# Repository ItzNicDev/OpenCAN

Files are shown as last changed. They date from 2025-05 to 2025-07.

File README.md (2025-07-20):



## 🔍 Project Overview

**OpenCAN** is a microcontroller-based project that reads live OBD-II data (e.g., turbo boost pressure or engine rpm) via Bluetooth and drives an analog pointer using a stepper motor. In a world where dashboards are becoming increasingly digital, **OpenCAN** revives the tactile, satisfying experience of real analog movement—because sometimes, a physical needle sweeping across a dial just feels more alive than pixels on a screen. The goal is to create smooth and responsive pointer movement despite delays in OBD-II data retrieval.

---

## 📑 Table of Contents
1. [🧰 Hardware Components](#-hardware-components)
2. [🏛️ Custom A-pillar trim](#%EF%B8%8F-custom-a-pillar-trim)
3. [🧊 Prepare 3D Printed Parts](#3d-printed-parts)
4. [🪚 Prepare Gauge Enclosure](#-prepare-gauge-enclosure)
5. [⚡️ Custom OpenCAN PCB](#%EF%B8%8F-custom-opencan-pcb)
6. [📟 Use different sensor](#-use-different-sensor)
7. [🔁 Pointer Movement Logic (Interpolation Algorithm)](#-pointer-movement-logic-interpolation-algorithm)
8. [🏃 Code-Flow-Diagram (for boost pressure)](#-code-flow-diagram-for-boost-pressure)
---

## 🧰 Hardware Components

### Core Modules

* 1x [ESP32-DEVKIT-V1](https://de.aliexpress.com/item/1005006128432036.html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) (30-Pin)
* 1x [X27168 Stepper Motor](https://de.aliexpress.com/item/1005001661473145.html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)
* 1x [ELM327](https://www.amazon.com/-/de/dp/B011NSX27A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)

### Power Supply
* 1x [2-Pin Screw Terminal](https://www.amazon.com/-/de/dp/B07QRHJ489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)
* 1x [CN3903 Buck Converter](https://de.aliexpress.com/item/1005003239596512.html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) (12V to 5V)
* 1x [TVS Diode](https://www.amazon.com/dp/B079KHXZHK?psc=1&ref_=cm_sw_r_cp_ud_ct_7PG0FPYTPC88BNJHQAFG_1) (1N6280A)
* 1x [470nF 16V Capacitor](https://de.aliexpress.com/item/1005006075263546.html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)
* 1x [Fuse Holder](https://www.amazon.com/-/de/dp/B074N1NMMX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) with [200mA Glass Fuse](https://www.amazon.com/-/de/dp/B074L7Z342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)

### 3D printed Components
* 1x [Gauge Adapter Ring](3D_models/gauge_adapter_ring.3mf)
* 1x [X27168 Adapter Plate](3D_models/x27168_adapter_plate.3mf)
* 1x Gauge Cup

### Additional Components

* 2x [15-Pin Header Socket](https://www.amazon.com/-/de/dp/B08DVGCTKT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)
* 3x [M3 Screws](https://de.aliexpress.com/item/1005004527586307.html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)
* 3x [M3 Threaded heat-set inserts](https://de.aliexpress.com/item/1005006472962973.html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)
* 1x [Custom OpenCAN PCB](#-pcb-layout) (See [Gerber Files](gerber_files) for further information)
* 1x [Guage Enclosure](https://de.aliexpress.com/item/1005007197636240.html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)

---
## 🏛️ Custom a-pillar trim
You may have noticed that the Gauge Cup is only available for the [Suzuki Swift Sport](3D_models/Suzuki_Swift_Sport/Gauge_Cup.3mf). This is because it would be impossible for me as a single person to cover a wide range of vehicles. That's why I only decided to draw such a gauge cup for my car. But in the following I will explain how to make your own gauge cup with simple household tools.

Of course, there are several ways to make a cover for the A-pillar. In the following, however, I will limit myself to the following:

### Molding via wire
Grab a wire that is easy to bend (copper, aluminum) and bend it around the A-pillar at fixed intervals. Stick the pieces of wire onto a sheet of paper with adhesive tape and scan it with a scanner. In the CAD program of your choice, you can arrange and trace the wires scanned by the scanner at the previously fixed distances.

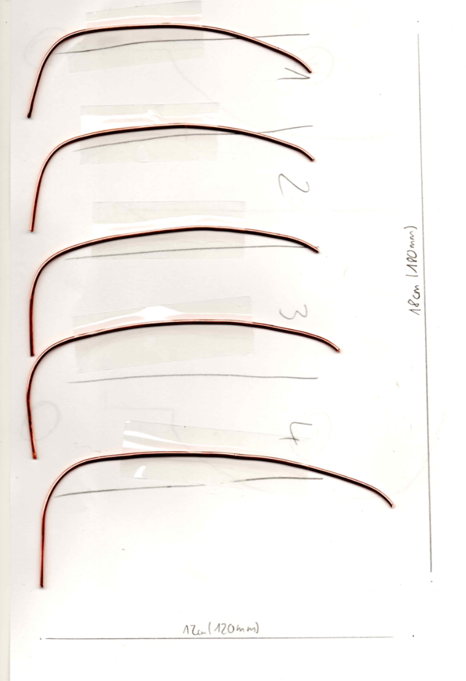
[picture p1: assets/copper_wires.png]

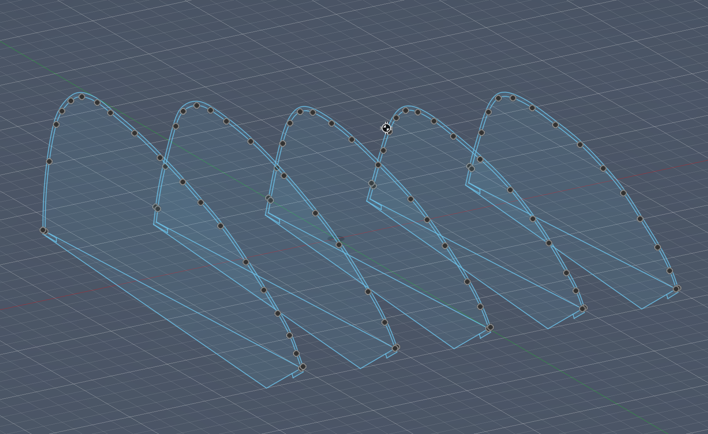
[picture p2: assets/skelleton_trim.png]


### Molding via 3D-Scan
An app called [Scaniverse](https://scaniverse.com/) is required for this approach. To make it easier for the app to scan or track the A-pillar, it is recommended to apply painter's tape to the surface to be scanned and to apply crosses with a black marker. Export the finished 3D model as an obj file and shape the A-pillar cover in any CAD program using the 3D model as a guide.

 

⚠️ Important: to ensure that the provided [gauge adapter ring](3D_models/gauge_adapter_ring.3mf) and the [X27168 adapter plate](3D_models/x27168_adapter_plate.3mf) fit, make sure that the hole for the gauge (blue area in the picture below) in the gauge cup has a diameter of 55.15mm or a radius of 27.575mm.

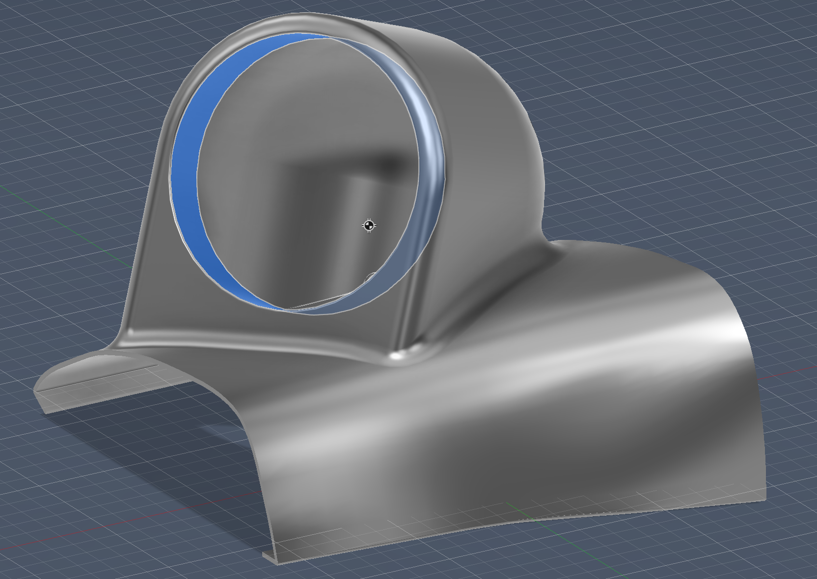
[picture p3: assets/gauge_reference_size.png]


---

## 🧊3D Printed Parts
* 1x [Gauge Cup](3D_models/Suzuki_Swift_Sport/Gauge_Cup.3mf) (you don't own a suzuki swift sport, see "🏛️ Custom A-pillar trim")
* 1x [Gauge Adapter Ring](3D_models/gauge_adapter_ring.3mf)
* 1x [X27168 Adapter Plate](3D_models/x27168_adapter_plate.3mf)

Don’t have a 3D printer? No problem! Services like [JLCPCB](https://jlc3dp.com/3d-printing-quote) now offer 3D printing too – you can upload the models directly and have them printed and shipped to you. Just make sure to choose a heat-resistant material since temperatures inside a car can get pretty high, especially in summer.

---

### 🧊 Prepare 3D Printed Adapter Plate
This part consists of melting the **threaded heat-set inserts** (M2) into the [X27168 adapter plate](3D_models/x27168_adapter_plate.3mf) both top and bottom and mounting the **X27168** step motor with the **M2 screws**.

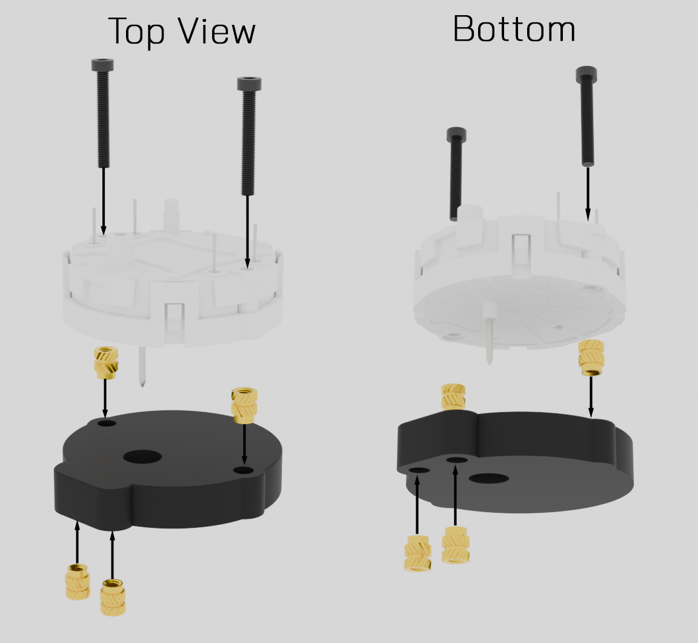
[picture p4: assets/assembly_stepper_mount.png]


## 🪚 Prepare Gauge Enclosure
Remove the nuts marked in the picture

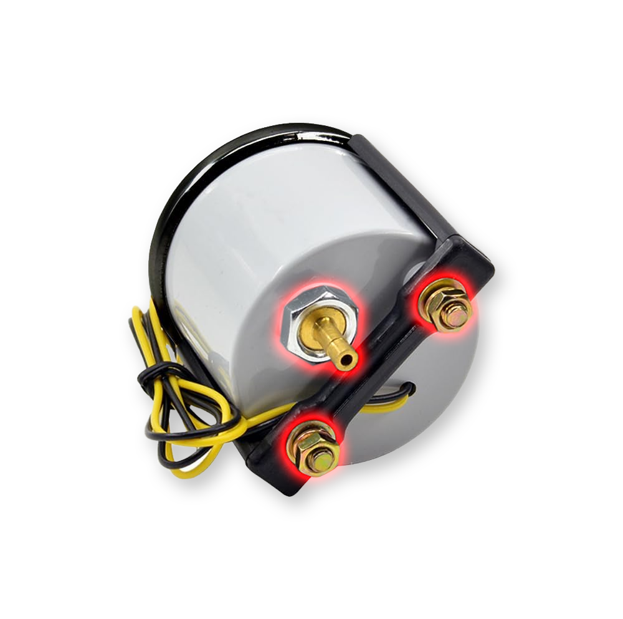
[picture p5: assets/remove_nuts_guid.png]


---
Cut along the marked line with a dremel to separate the glass part from the rest. Carefully remove the unit from the cut-open enclosure and put it away in the meantime and sand the rough edges of the enclosure. Be careful not to scratch the front of the glass while cutting and sanding. It helps to cover it with masking tape.

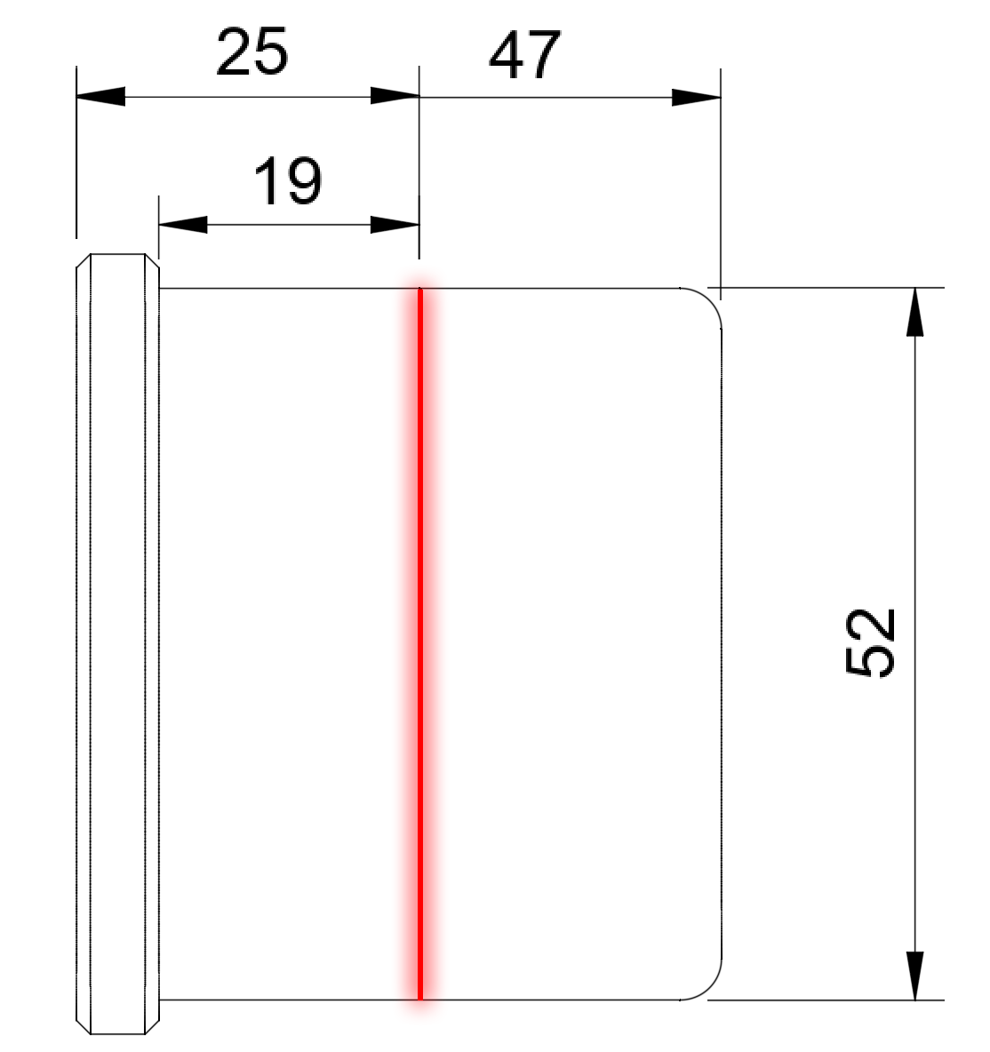
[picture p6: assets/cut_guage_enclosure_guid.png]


---

Take your unit from before and carefully lift the plastic sheet scale at one of the red marked tabs to remove it from the plastic cage completely.



---

Now that the plastic sheet scale has been removed, 2 screws will appear. Unscrew these and you will notice that the circuit board (white), the plastic cage (black plastic with conical top in the middle) and the rear brass part are now separated from each other. The brass part is no longer important for us and has no further use.




---

Now the plastic sheet scale, the plastic cage (black plastic with conical top in the middle) and the pcb (background lighting) can be combined with the previously assembled adapter plate.



---

## ⚡️ Custom OpenCAN PCB
### Schematic

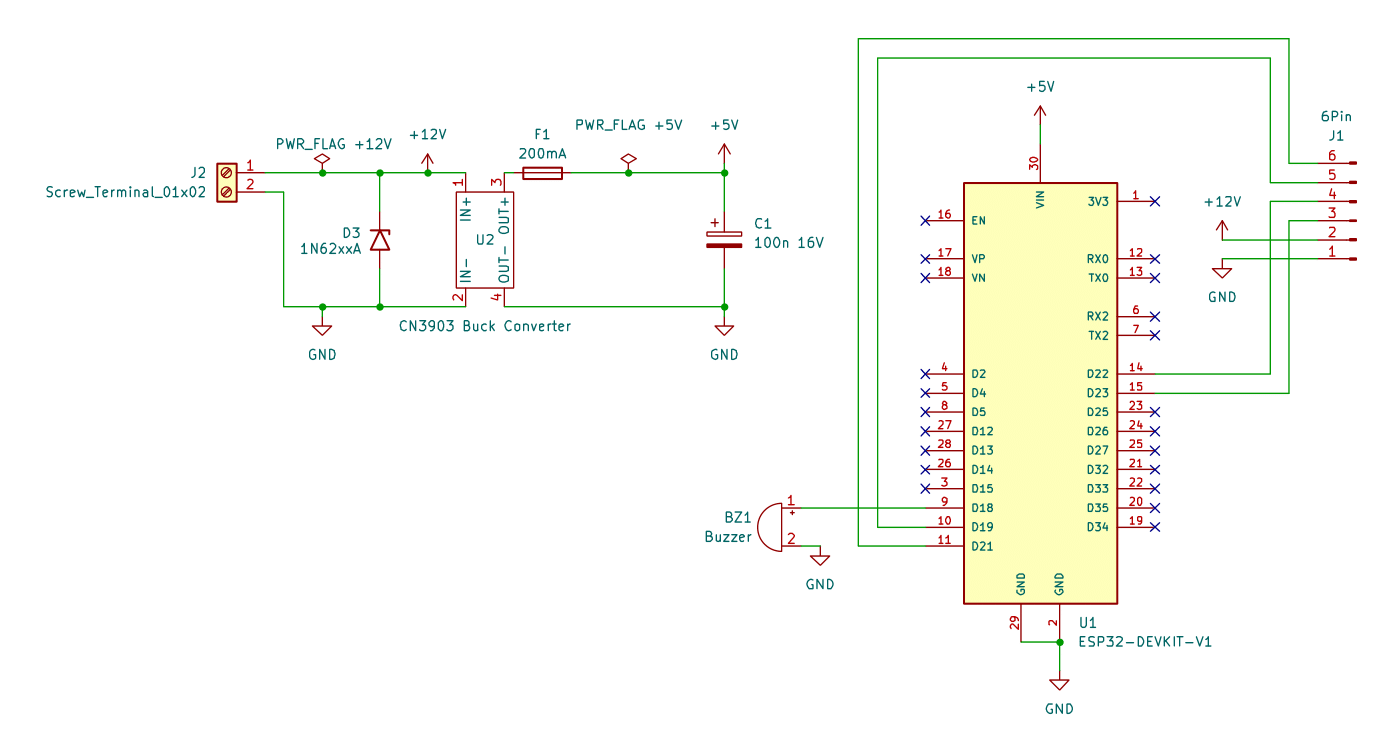
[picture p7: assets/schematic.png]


---

### PCB
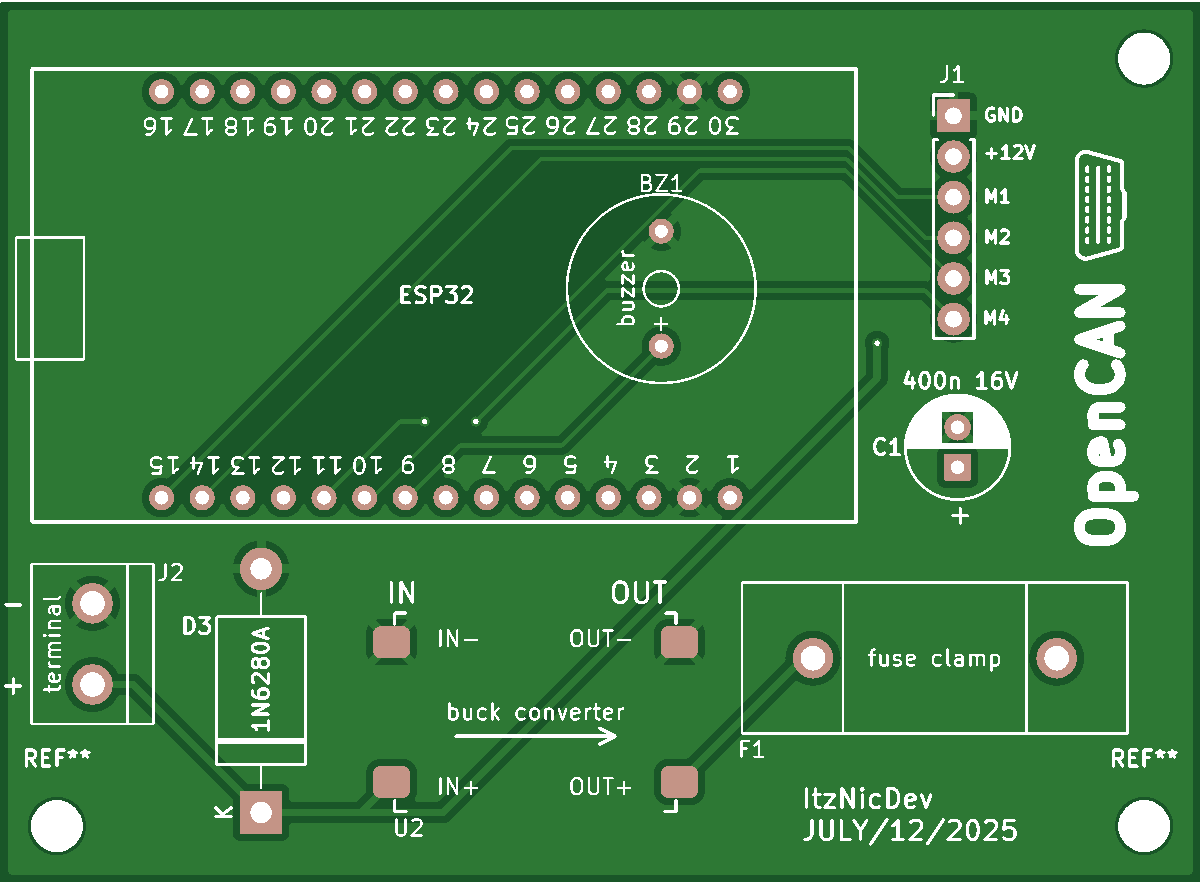
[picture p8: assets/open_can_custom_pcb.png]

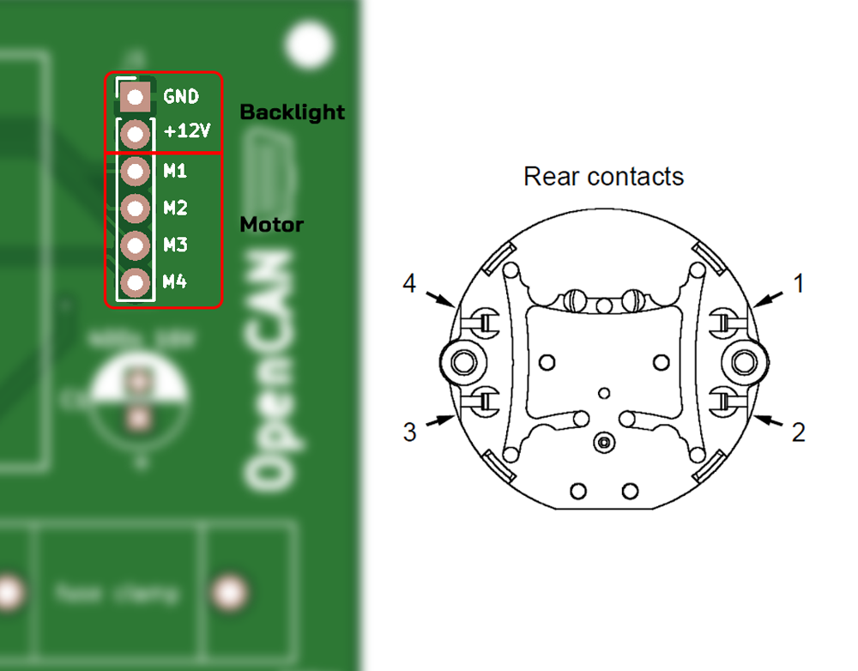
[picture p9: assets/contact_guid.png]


---

### Ordering
The custom pcb can be ordered from manufacturers such as [JLCPCB](https://cart.jlcpcb.com/quote?spm=Jlcpcb.Homepage.1006). In the case of [JLCPCB](https://cart.jlcpcb.com/quote?spm=Jlcpcb.Homepage.1006), it is recommended to choose the lead-free HASL for the surface finish for health reasons. The PCB color can also be selected, but this may incur additional costs. Also make sure that a PCB thickness of 1.6 mm is selected

---

### ⚡ Electrical Flow Diagram

```text
12V (Car Battery)
├── TVS Diode
├── LED (optional)
├── Buck Converter (12V → 5V)
│   ├── Fuse (200mA)
│   ├── Capacitor (470nF)
│   └── ESP32
│       ├── Buzzer
│       └── Stepper Motor (X27168)
```

---

## 📟 Use different sensor
Of course, it is also possible to read from sensors other than boost pressure or rpm. There is a detailed documentation on [Wikipedia](https://en.wikipedia.org/wiki/OBD-II_PIDs) which lists a number of sensors including PIDs and conversion formulas. OpenCAN is designed so that other sensor types can be added relatively easily. 

To add a new sensor type you must first find the correct PID and the conversion formula. Now you have to define a new [sensor type](platformio_project/include/ObdSensorType.h). Next, the new sensor type must be specified in the [obdSensorHexMap](platformio_project/include/ELM327Driver.h#L20) with [sensor type](platformio_project/include/ObdSensorType.h) and PID. Last but not least, [decodeSensorValue](platformio_project/src/ObdUtils.cpp#L19) must be extended by a case. This contains the handling of the decoding.

---

## 🔁 Pointer Movement Logic (Interpolation Algorithm)

### ⚠️ The Problem

OBD-II data via Bluetooth (e.g., ELM327) introduces blocking delays (typically 80–150 ms). During this blocking time, the microcontroller can't update the motor, resulting in jerky and unresponsive pointer behavior.

### 💡 The Solution: Linear Interpolation

To solve this, OpenCAN simulates smooth transitions between OBD data points using linear interpolation:

#### 1. Periodic, Blocking Data Fetch

* A new target value is fetched every `obdRequestInterval` (e.g., 150ms)
* When new data arrives:

  * Start point (`V0`) is set to the previous target value
  * End point (`V1`) is the newly received value
  * Start time (`t0`) is recorded

#### 2. Continuous Interpolation in Loop

* On every iteration of the `loop()`, if not blocked by data fetch:

  * Calculate progress:

    ```
    progress = (currentTime - t0) / obdRequestInterval
    ```
  * Calculate interpolated target:

    ```
    V_interpolated = V0 + (V1 - V0) * progress
    ```
  * Send `V_interpolated` to `motor.setTargetAngle()`
  * `motor.update()` ensures the motor continuously moves towards this value

### ✅ Result

* The pointer moves smoothly between data points
* Movement appears fluid and responsive, independent of the actual data delay

---

## 🏃 Code-Flow-Diagram (for boost pressure)
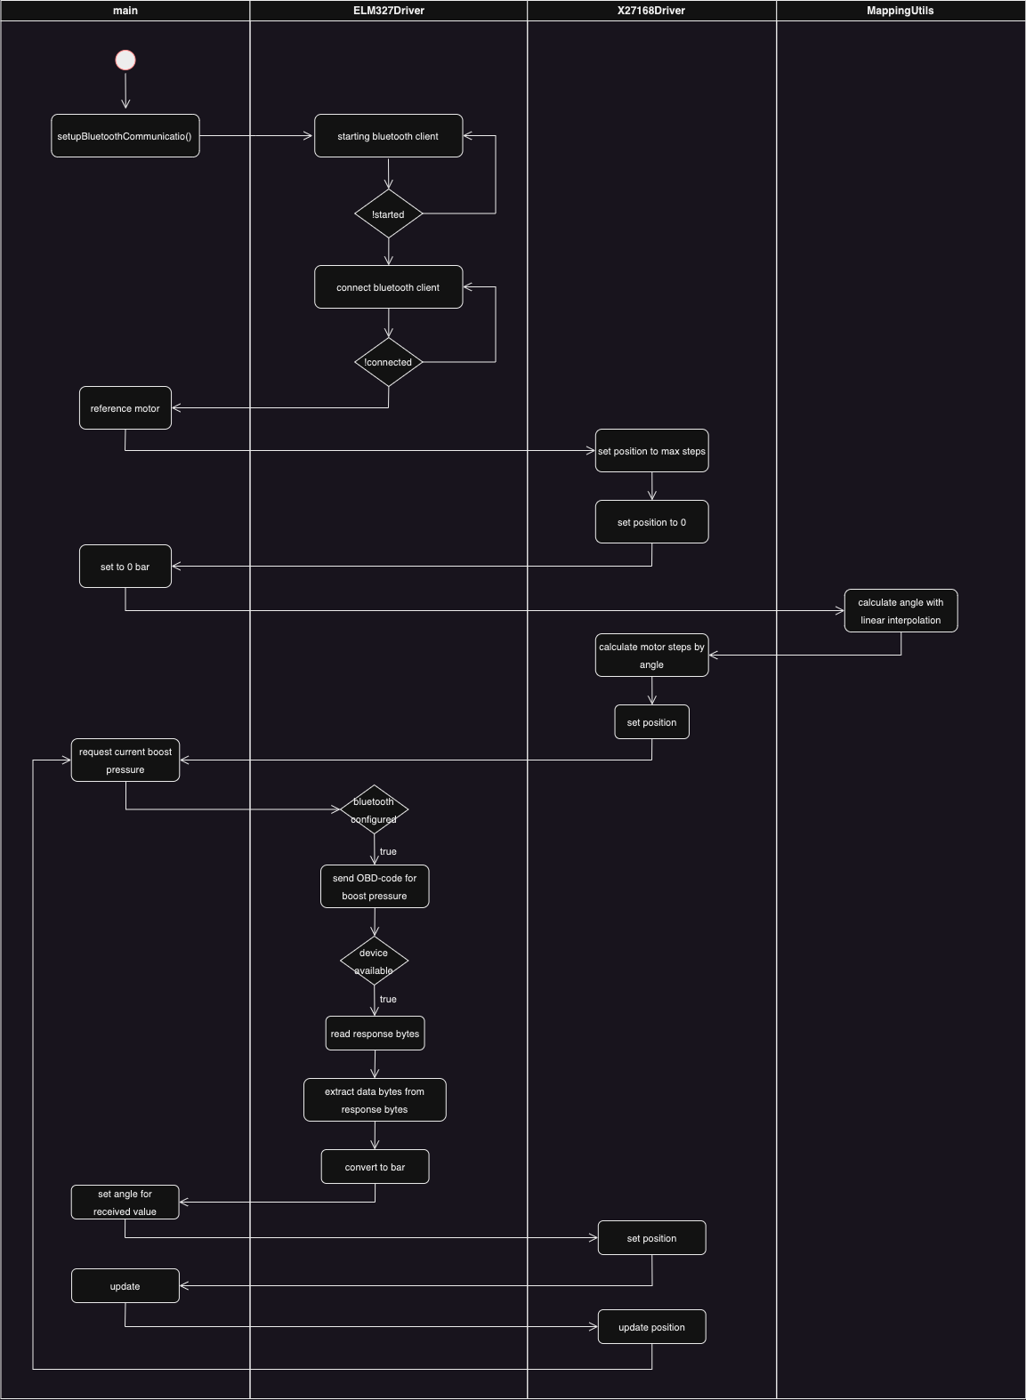
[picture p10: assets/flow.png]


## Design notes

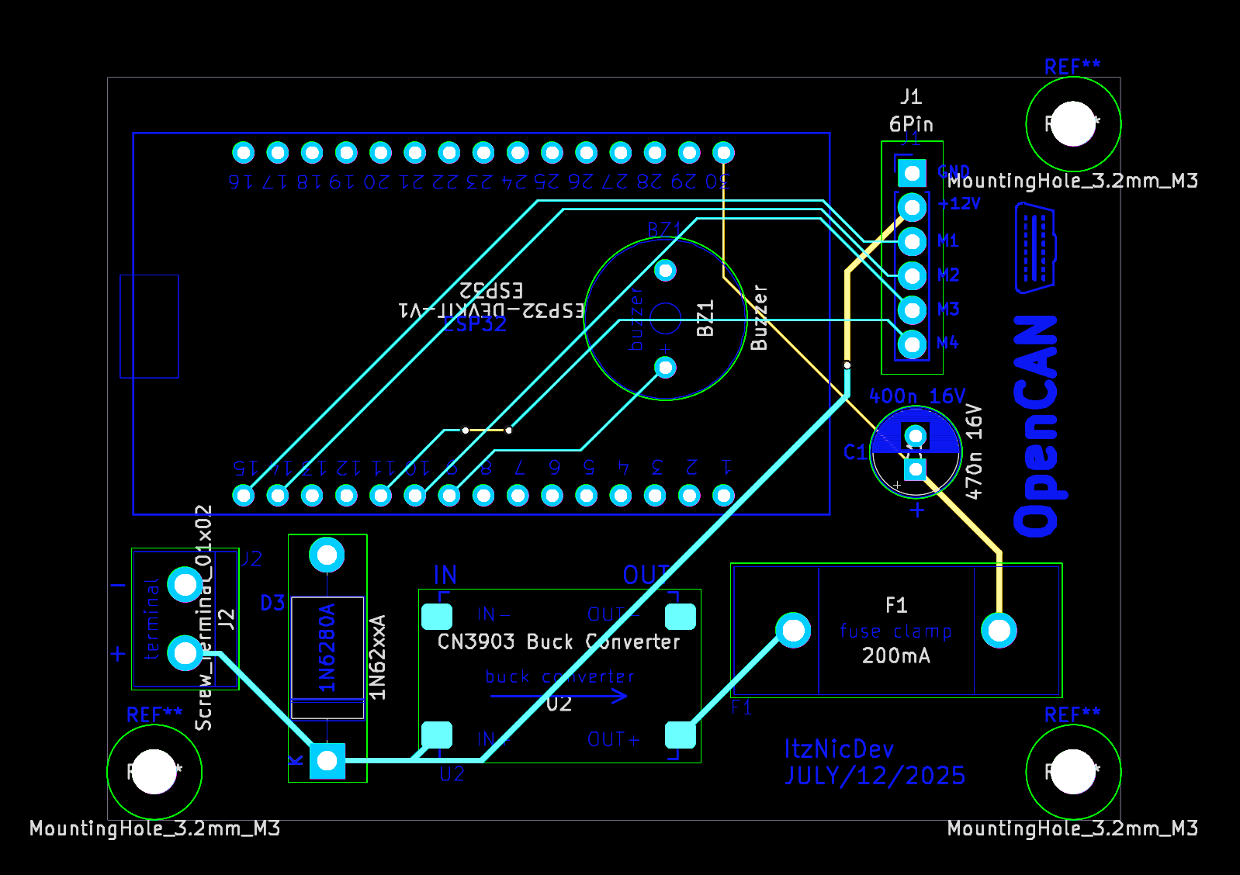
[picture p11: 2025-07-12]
assets/pcb_design.png

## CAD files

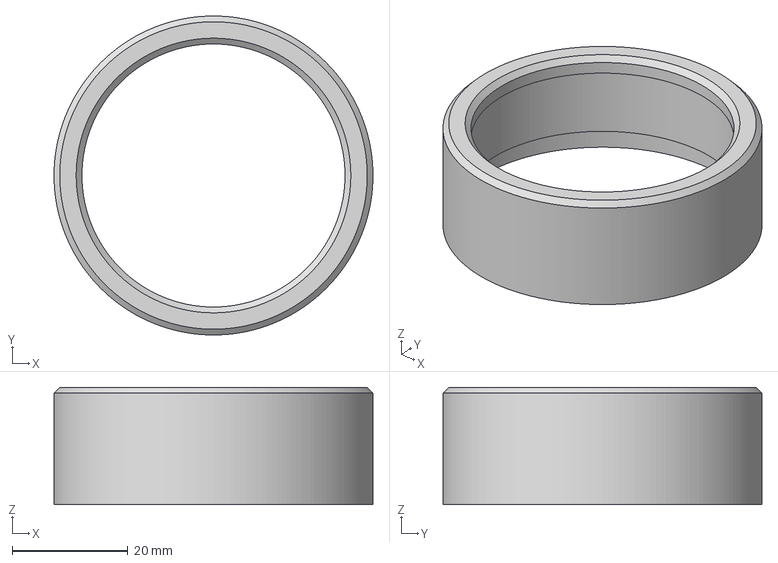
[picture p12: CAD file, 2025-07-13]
3D_models/gauge_adapter_ring.3mf
55.0 x 55.0 x 20.2 mm

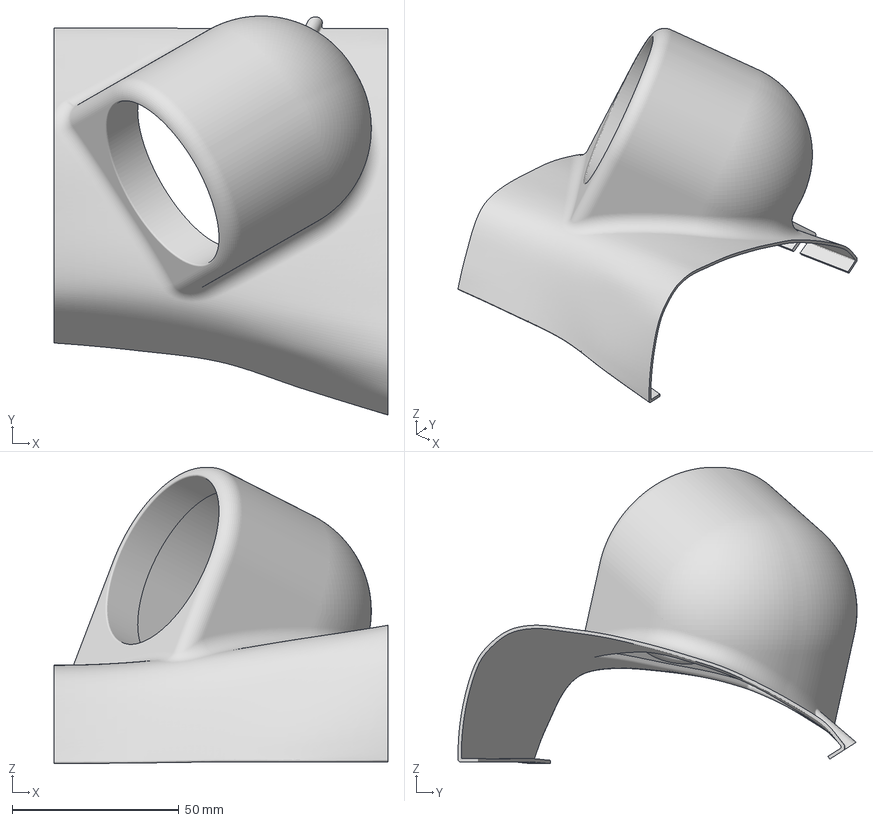
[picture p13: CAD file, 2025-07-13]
3D_models/Suzuki_Swift_Sport/Gauge_Cup.3mf
100.0 x 119.6 x 88.8 mm

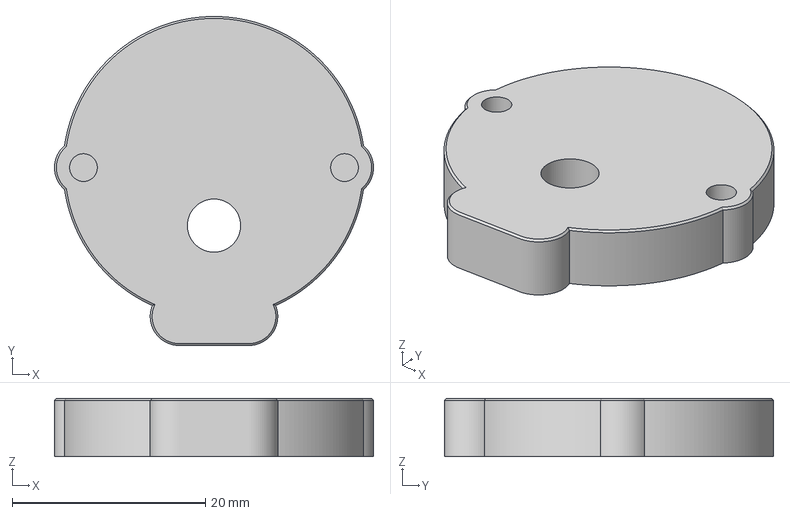
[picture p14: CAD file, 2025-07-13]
3D_models/x27168_adapter_plate.3mf
33.0 x 34.0 x 6.00 mm

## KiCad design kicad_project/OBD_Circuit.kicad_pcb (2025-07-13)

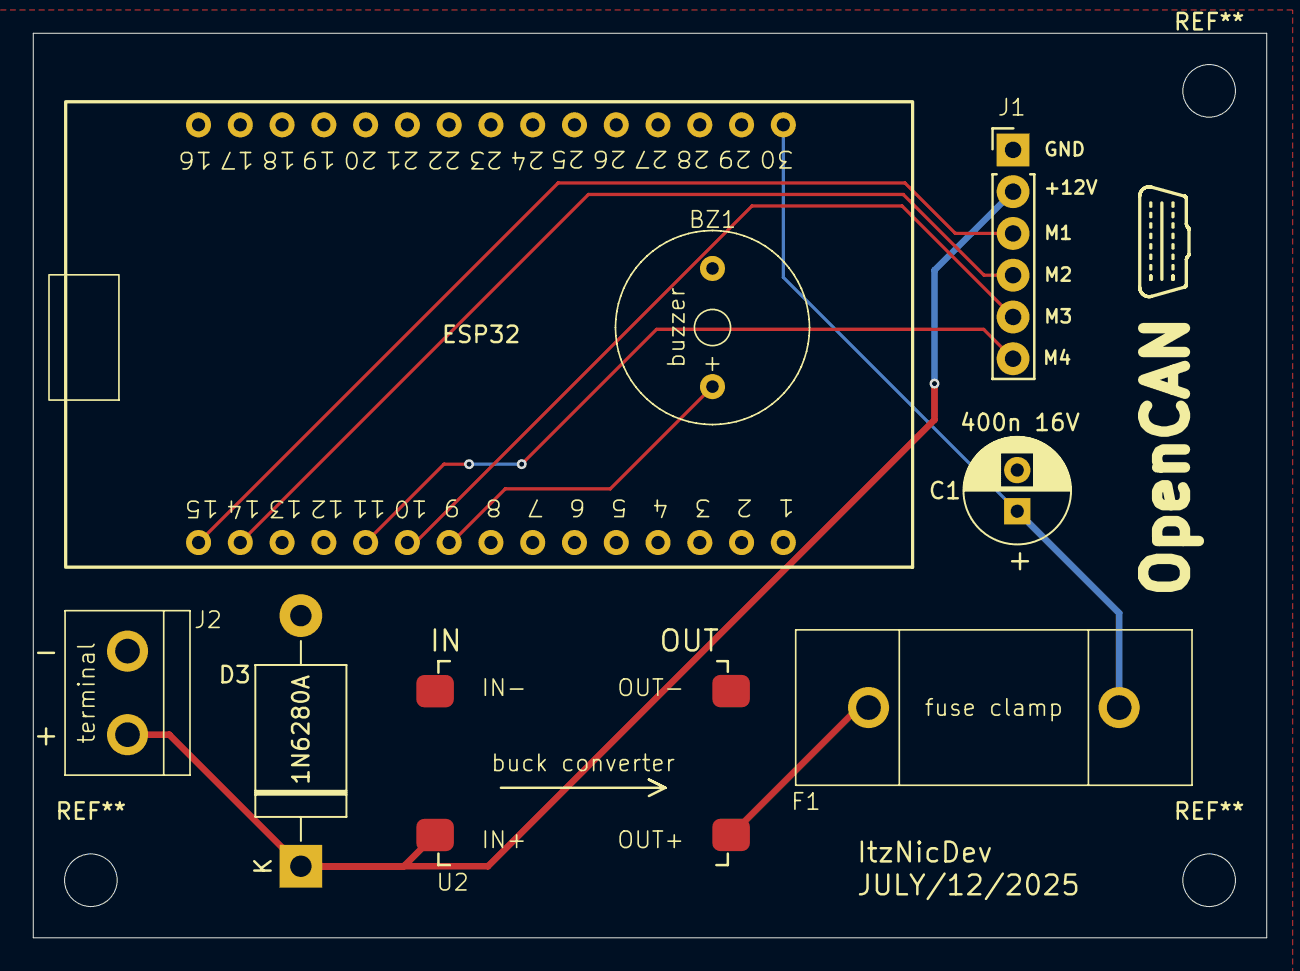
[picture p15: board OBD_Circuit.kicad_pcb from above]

Board: 4 copper layers, 75.0 x 55.0 mm, 8 parts (0 on the bottom side), 9 nets.

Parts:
BZ1: Buzzer; buzzer
C1: 470n 16V; CP_Radial_D6.3mm_P2.50mm
D3: 1N62xxA; D_DO-201AE_P15.24mm_Horizontal
ESP32: ESP32-DEVKIT-V1; esp32_30pin
F1: 200mA; fuse_clamp
J1: 6Pin; pin_connector_6pin
J2: Screw_Terminal_01x02; screw_terminal_2pin
U2: CN3903 Buck Converter; cn3903_buck_converter

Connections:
+5V: C1.1, ESP32.30 (VIN), F1.2
+12V: D3.1 (A1), J1.2, J2.1, U2.1 (IN+)
GND: BZ1.2 (-), C1.2, D3.2 (A2), ESP32.2 (GND), ESP32.29 (GND), J1.1, J2.2, U2.2 (IN-), U2.4 (OUT-)
unnamed: BZ1.1 (+), ESP32.9 (D18)
unnamed: ESP32.15 (D23), J1.3
unnamed: ESP32.14 (D22), J1.4
unnamed: ESP32.10 (D19), J1.5
unnamed: ESP32.11 (D21), J1.6
unnamed: F1.1, U2.3 (OUT+)

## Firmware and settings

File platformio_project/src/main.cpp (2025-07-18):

#include "Arduino.h"
#include "ObdUtils.h"
#include "X27168Driver.h"
#include "MappingUtils.h"
#include "ELM327Driver.h"

MappingUtils mappingUtils;
X27168Driver motor(945, 14, 16, 17, 18);
uint8_t obdAddress[] = {0x00, 0x1D, 0xA5, 0x07, 0x52, 0x39};
ELM327Driver elm327(obdAddress);

// Zeitsteuerung für OBD-Abfragen
unsigned long lastObdRequestTime = 0;
// WICHTIG: Setze diesen Wert auf die MAXIMALE Dauer, die elm327.getResponse() blockieren kann
// plus einen kleinen Puffer. Miss das genau aus!
const unsigned long obdRequestInterval = 80; // Beispiel: Wenn getResponse bis zu 120ms dauert, nimm 150ms.

// Für die Glättung der OBD-Werte
float rawDegree = 0; // Der letzte ROH-Winkel von OBD (muss global sein)
float smoothedDegree = mappingUtils.boostToDegree(0);
const float smoothingFactor = 0.65; // Dein Glättungsfaktor

// Für die Interpolation
float lastObdTargetDegree = mappingUtils.boostToDegree(0); // Das ZIEL, das beim LETZTEN OBD-Update gesetzt wurde
float nextObdTargetDegree = mappingUtils.boostToDegree(0); // Das ZIEL, das beim NÄCHSTEN OBD-Update erreicht werden soll

void setup() {
  Serial.begin(115200);
  Serial.println("System Start...");
    motor.reference();


  elm327.setupBluetoothComunication();
  Serial.println("Bluetooth setup complete.");

  motor.reference();
  Serial.println("Motor referenced.");

  delay(1000);

  // Setze die initialen Ziele auf den Leerlaufwert
  rawDegree = mappingUtils.boostToDegree(0);
  smoothedDegree = rawDegree;
  lastObdTargetDegree = rawDegree;
  nextObdTargetDegree = rawDegree;

  motor.setTargetAngle(smoothedDegree); // Setze das erste Ziel für den Motor
}

void loop()
{
  // Teil 1: OBD-Daten alle 'obdRequestInterval' Millisekunden abrufen (BLOCKIEREND)
  // Wenn es Zeit für ein neues OBD-Update ist:
  if (millis() - lastObdRequestTime >= obdRequestInterval)
  {
    lastObdRequestTime = millis(); // Zeitpunkt der letzten Abfrage aktualisieren

    // DEBUG: Messen, wie lange die OBD-Abfrage dauert
    unsigned long obdStartTime = micros();
    float boost = elm327.getResponse(ObdSensorType::Boost); // <-- Hier blockiert es!
    unsigned long obdEndTime = micros();
    Serial.print("OBD response time: ");
    Serial.print((obdEndTime - obdStartTime) / 1000.0); // In Millisekunden
    Serial.println(" ms");

    // Speichere den zuletzt gelesenen Rohwert und das vorherige Ziel
    // Diese Werte werden für die Interpolation im nächsten Intervall benötigt
    lastObdTargetDegree = nextObdTargetDegree; // Das bisherige "Next-Ziel" wird zum "Last-Ziel"
    
    rawDegree = mappingUtils.boostToDegree(boost); // Hole den NEUEN Roh-Winkel

    // Wende Glättung auf den NEUEN OBD-Wert an, um das NÄCHSTE ZIEL zu bestimmen
    smoothedDegree = (rawDegree * smoothingFactor) + (smoothedDegree * (1.0 - smoothingFactor));
    nextObdTargetDegree = smoothedDegree; // Das ist das tatsächliche ZIEL, das der Motor in 'obdRequestInterval' erreichen soll

    // Optional: Für Debugging, den Sprung in den Zielen verfolgen
    // Serial.print("New OBD Target: ");
    // Serial.println(nextObdTargetDegree);
  }

  // Teil 2: Interpolation des Zielwerts (immer nicht-blockierend!)
  // Berechne einen Zwischenwert, der den Zeiger flüssig zum nextObdTargetDegree bewegt.
  // Das passiert in JEDEM loop()-Durchlauf.

  float interpolatedDegree;
  unsigned long timeElapsed = millis() - lastObdRequestTime; // Zeit seit der letzten OBD-Abfrage

  // Wenn die Zeit abgelaufen ist oder noch kein Intervall gestartet, bleibe beim letzten Ziel
  if (timeElapsed >= obdRequestInterval) {
      interpolatedDegree = nextObdTargetDegree; // Sollte hier eigentlich nicht passieren, da der if-Block greift
  } else {
      // Berechne den Fortschritt als Verhältnis der Zeit zum Gesamtintervall
      float progress = (float)timeElapsed / obdRequestInterval;
      
      // Lineare Interpolation zwischen lastObdTargetDegree und nextObdTargetDegree
      interpolatedDegree = lastObdTargetDegree + (nextObdTargetDegree - lastObdTargetDegree) * progress;
  }
  
  // Setze das interpolierte Ziel für den Motor
  motor.setTargetAngle(interpolatedDegree);

  // Teil 3: Motor in jedem loop()-Durchlauf aktualisieren (NICHT blockierend)
  // Das ist ABSOLUT ENTSCHEIDEND für die Motorbewegung!
  motor.update();

  // KEIN delay() HIER! Ein delay() würde motor.update() massiv ausbremsen.
}

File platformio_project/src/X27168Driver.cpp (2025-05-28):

#include "X27168Driver.h"
#include <MappingUtils.h>

X27168Driver::X27168Driver(unsigned int steps, unsigned char pin1, unsigned char pin2, unsigned char pin3, unsigned char pin4)
    : _pin1(pin1), _pin2(pin2), _pin3(pin3), _pin4(pin4), _steps(steps), _motor(steps, pin1, pin2, pin3, pin4)
{
}

void X27168Driver::reference()
{
    _motor.setPosition(_steps);
    _motor.updateBlocking();
    _motor.setPosition(0);
    _motor.updateBlocking();
}

void X27168Driver::moveToAngle(int angle)
{
    _motor.setPosition(angle * 3);
    _motor.updateBlocking();
    delay(1);
}

void X27168Driver::setTargetAngle(float angle) // Parameter ist jetzt float
{
    // ACHTUNG: Hier wird MappingUtils::boostToDegree() verwendet.
    // Da MappingUtils 'mappingUtils' ein GLOBALES Objekt im Hauptsketch ist,
    // kann es hier nicht direkt als '_mappingUtils' aufgerufen werden,
    // es sei denn, es ist ein Member der X27168Driver Klasse (was es nicht ist).
    // Wenn 'boostToDegree' eine statische Methode von MappingUtils wäre, ginge 'MappingUtils::boostToDegree'.
    //
    // Da 'degree' schon vom Hauptsketch kommt (nach der Umwandlung durch mappingUtils),
    // sollte 'angle' hier bereits der fertige "Gradwert" sein, den der Motor verwenden kann.
    // Die Konvertierung in Schritte * 3.0f ist dein Skalierungsfaktor für den Motor.

    int targetStep = static_cast<int>(angle * 3.0f); // Konvertiere float-Winkel in int-Schritte

    // Stelle sicher, dass der Zielschritt innerhalb des gültigen Bereichs liegt
    // (nicht kleiner als 0 und nicht größer als _steps - 1)
    if (targetStep < 0)
        targetStep = 0;
    if (targetStep >= _steps) // Muss <= _steps - 1 sein, wenn _steps die Anzahl der Schritte ist
        targetStep = _steps - 1; // Die SwitecX25 ist 0-basiert bis steps-1

    _motor.setPosition(targetStep); // Setzt das Ziel für den SwitecX25-Motor
    // WICHTIG: KEIN _motor.updateBlocking() oder delay() hier!
    // Die Bewegung wird durch regelmäßige Aufrufe von update() im loop() gesteuert.
}

void X27168Driver::zero()
{
    _motor.zero();
}

void X27168Driver::update()
{
    _motor.update();
}

void X27168Driver::test()
{
    reference();
    for (float i = -1.0; i <= 2.0; i = i + 0.5)
    {
        moveToAngle(_mappingUtils.boostToDegree(i));
        delay(1000);
    }
    for (float i = 2.0; i >= -1.0; i = i - 0.5)
    {
        moveToAngle(_mappingUtils.boostToDegree(i));
        delay(1000);
    }

    for (float i = -1.0; i <= 2.0; i = i + 0.1)
    {
        moveToAngle(_mappingUtils.boostToDegree(i));
        delay(50);
    }

    for (float i = 2.0; i >= -1.0; i = i - 0.1)
    {
        moveToAngle(_mappingUtils.boostToDegree(i));
        delay(50);
    }

    for (float i = -1.0; i <= 2.0; i = i + 0.1)
    {
        moveToAngle(_mappingUtils.boostToDegree(i));
        delay(10);
    }

    for (float i = 2.0; i >= -1.0; i = i - 0.1)
    {
        moveToAngle(_mappingUtils.boostToDegree(i));
        delay(10);
    }

    for (float i = -1.0; i <= 2.0; i = i + 0.1)
    {
        moveToAngle(_mappingUtils.boostToDegree(i));
        delay(5);
    }

    for (float i = 2.0; i >= -1.0; i = i - 0.1)
    {
        moveToAngle(_mappingUtils.boostToDegree(i));
        delay(5);
    }
}

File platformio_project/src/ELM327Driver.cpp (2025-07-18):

#include "ELM327Driver.h"
#include "ObdUtils.h"

ELM327Driver::ELM327Driver(uint8_t adress[6])
{
    for (int i = 0; i < 6; i++)
    {
        _adress[i] = adress[i];
    }
}

bool bluetoothConfigured = false;

// char* str_rm_ws(char* str) {
//   if (str == nullptr) {
//     return nullptr;
//   }

//   int i = 0;
//   int j = 0;
//   while (str[i] != '\0') {
//     if (str[i] != ' ') {
//       str[j] = str[i];
//       j++;
//     }
//     i++;
//   }
//   str[j] = '\0';
//   return str;
// }

float ELM327Driver::getResponse(ObdSensorType obdSensorType)
{
    if (bluetoothConfigured)
    {

        ELM327Driver::_serialBT.println(ELM327Driver::_obdSensorHexMap[obdSensorType]);

        if (ELM327Driver::_serialBT.available())
        {
            char response[64];
            size_t index = 0;

            while (true)
            {
                if (ELM327Driver::_serialBT.available())
                {
                    char c = ELM327Driver::_serialBT.read();
                    if (c == '>')
                    {
                        response[index] = '\0';
                        break;
                    }
                    if (index < sizeof(response) - 1)
                    {
                        response[index++] = c;
                    }
                    else
                    {
                        // Buffer full, terminate string and break to avoid overflow
                        response[sizeof(response) - 1] = '\0';
                        Serial.println("Warning: OBD response too long, truncated!");
                        break;
                    }
                }
            }
            ObdUtils obdUtils;

            Serial.println("Before transforming " + String(response));

            float decodedResponse =  obdUtils.decodeSensorValue(response, obdSensorType);
            Serial.println(decodedResponse);

            return decodedResponse; // <-- ADD THIS LINE!
        }
        // If no response available, return 0
        return 0; // <-- ADD THIS LINE!
    }
    else
    {
        Serial.println("Bluetooth needs to be configured. Use 'setupBluetoothComunication' for setup");
        return 0;
    }
}

void ELM327Driver::setupBluetoothComunication()
{
    int attempts = 1;
    bool connectionSuccessful = false;

    Serial.println("ESP32 Bluetooth Client startet...");

    if (!ELM327Driver::_serialBT.begin("ESP32_Client", true))
    {
        Serial.println("Bluetooth konnte nicht gestartet werden.");
        while (1)
            ;
    }

    Serial.println("Bluetooth als Client gestartet");
    bluetoothConfigured = true;
    while (!connectionSuccessful)
    {
        if (ELM327Driver::_serialBT.connect(ELM327Driver::_adress))
        {
            Serial.println("Connection successful");
            connectionSuccessful = true;
        }
        else
        {
            Serial.println("Connection failed!");
            delay(3000);
        }
        attempts++;
    }
}

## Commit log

2025-05-19 feature - added test function for motor
2025-07-13 added gerber files
    [OBD_Circuit-B_Mask.gbs, OBD_Circuit-B_Paste.gbp, OBD_Circuit-B_Silkscreen.gbo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]
2025-07-13 kicad files added
    [OBD_Circuit.kicad_pcb, OBD_Circuit.kicad_sch]
2025-07-13 added 3d model and ziped gerber files
    [Gauge_Cup.3mf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]
